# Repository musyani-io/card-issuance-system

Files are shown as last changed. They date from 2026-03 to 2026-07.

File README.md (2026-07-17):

# Smart ID Card Issuance Kiosk

A prototype university ID-card issuance system that combines a Raspberry Pi application, OCR-based card registration, local SQLite storage, student authentication, SMS/email credential delivery, and an Arduino Mega hardware-control prototype.

> **Project status:** Active prototype. The software modules are partly integrated, while physical card dispensing is still simulated in the current Kivy application.

---

## Table of Contents

- [Project Overview](#project-overview)
- [Current Implementation Status](#current-implementation-status)
- [System Workflow](#system-workflow)
- [Architecture](#architecture)
- [Technology Stack](#technology-stack)
- [Repository Structure](#repository-structure)
- [Kiosk Application Setup](#kiosk-application-setup)
- [Database Setup](#database-setup)
- [Mock University API Setup](#mock-university-api-setup)
- [Running the OCR Pipeline](#running-the-ocr-pipeline)
- [Running the Kiosk UI](#running-the-kiosk-ui)
- [Firmware Setup](#firmware-setup)
- [Testing](#testing)
- [Configuration Reference](#configuration-reference)
- [Security Design](#security-design)
- [Known Limitations](#known-limitations)
- [Development Priorities](#development-priorities)
- [Documentation and Hardware Files](#documentation-and-hardware-files)
- [License](#license)

---

## Project Overview

The project is intended to automate the storage and collection of university identity cards.

The repository currently contains four main parts:

1. **Raspberry Pi kiosk application**
   - Kivy touchscreen interface
   - Student registration-number entry
   - OTP verification
   - Temporary and permanent PIN handling
   - SQLite card and authentication records
   - Session timeout and lockout screens

2. **OCR and card-ingestion pipeline**
   - Camera image capture
   - Card contour detection
   - Perspective correction
   - Registration-number region extraction
   - Tesseract OCR
   - University API lookup
   - Local card-slot assignment

3. **Mock university database API**
   - Flask REST API
   - MySQL-backed student lookup
   - API-key authentication
   - Student-field normalization

4. **Hardware-control prototype**
   - Arduino Mega 2560 PlatformIO project
   - SPI frame reception from Raspberry Pi
   - Servo test routines
   - Hardware, PCB, mechanical, simulation, and datasheet files

---

## Current Implementation Status

| Subsystem | Current state |
| --- | --- |
| Kivy student collection interface | Implemented |
| Registration-number validation | Implemented |
| Local SQLite database | Implemented |
| OTP generation and verification | Implemented |
| Temporary PIN and permanent PIN storage | Implemented |
| Bcrypt credential hashing | Implemented |
| Authentication lockout logic | Implemented |
| SMS delivery through BRIQ Solutions | Implemented; requires credentials |
| Email delivery through Gmail SMTP | Implemented; requires credentials |
| University API client | Implemented |
| Flask/MySQL mock university API | Implemented; requires local configuration and database |
| Camera image capture | Implemented |
| Card contour and perspective correction | Implemented |
| Tesseract OCR extraction | Implemented |
| Card ingestion and three-slot assignment | Implemented |
| Raspberry Pi SPI sender | Basic two-byte status frames implemented |
| Arduino Mega SPI receiver | Basic frame reception implemented |
| Servo prototype | Implemented at firmware-test level |
| Staff batch-loading Kivy interface | Not integrated into `main.py` |
| Automatic motorised card dispensing | Not integrated; simulated in `main.py` |
| Complete carousel/conveyor control | Not implemented in the checked-in firmware |
| Production deployment and enclosure | Not complete |

The repository documentation has been updated to reflect the physical system. The firmware targets an **Arduino Mega 2560**, and the SQLite ingestion logic assigns a maximum of **three active slots** (0, 1, 2) matching the 3-compartment carousel design.

---

## System Workflow

### Card registration and ingestion

```text
Camera capture
      |
      v
Card contour detection
      |
      v
Perspective correction
      |
      v
Registration-number ROI extraction
      |
      v
Tesseract OCR
      |
      v
University API lookup
      |
      v
Generate OTP and temporary PIN when required
      |
      v
Store student, authentication, card, and audit records in SQLite
      |
      v
Send credentials through SMS and email
```

### Student card collection

```text
Idle screen
      |
      v
Enter registration number
      |
      v
Check local student and card record
      |
      v
Enter six-digit OTP
      |
      +-------------------------------+
      |                               |
      v                               v
Temporary PIN exists             Permanent PIN exists
      |                               |
      v                               |
Verify temporary PIN                  |
      |                               |
      v                               |
Create permanent PIN                  |
      +---------------+---------------+
                      |
                      v
Load assigned slot
                      |
                      v
Mark card as collected
                      |
                      v
Simulated dispensing delay
                      |
                      v
Confirmation screen
```

> The returning-student branch currently proceeds after OTP verification without displaying the permanent-PIN entry screen. The authentication module contains permanent-PIN verification logic, but that step is not connected to the returning-student path in `main.py`.

---

## Architecture

```mermaid
flowchart LR
    CAM[Camera or phone webcam] --> OCR[OpenCV and Tesseract OCR]
    OCR --> INGEST[Card ingestion service]
    API[Flask university API] --> INGEST
    MYSQL[(University MySQL database)] --> API
    INGEST --> SQLITE[(Local SQLite database)]
    INGEST --> SMS[BRIQ SMS API]
    INGEST --> EMAIL[Gmail SMTP]
    UI[Kivy touchscreen UI] --> SQLITE
    UI --> AUTH[OTP and PIN authentication]
    AUTH --> SQLITE
    UI -. basic status frames .-> SPI[Raspberry Pi SPI master]
    SPI --> MEGA[Arduino Mega 2560]
    MEGA --> SERVO[Servo prototype]
```

### Raspberry Pi application layer

The `kiosk_brain` application is responsible for:

- Kivy user-interface screens
- Student-session state
- Local database access
- OTP and PIN verification
- OCR processing
- University API communication
- SMS and email credential delivery
- Basic SPI transmission

### Local database layer

SQLite stores:

- Students
- Cards and assigned slots
- OTP and PIN hashes
- Authentication attempts and lockouts
- Audit events
- Batch metadata

### University API layer

The mock API provides:

```http
GET /students/<registration_number>
X-API-Key: <configured-key>
```

It reads student records from MySQL and normalizes alternative field names such as:

- `reg_number` or `registration_number`
- `last_name` or `surname`
- `phone` or `phone_number`
- `status` or `registration_status`

### Hardware-control layer

The current firmware is a PlatformIO Arduino project for the Mega 2560. It currently:

- Configures the Mega as an SPI slave
- Receives two-character ASCII frames
- Prints received frames through the serial monitor
- Runs prototype servo movement routines

It does not yet implement the complete carousel, conveyor, sensor, lock, or dispensing sequence described in the planning documents.

---

## Technology Stack

### Application

- Python
- Kivy
- OpenCV
- Tesseract OCR through `pytesseract`
- SQLite
- Requests
- Bcrypt
- `spidev`
- Pytest

### API

- Flask
- MySQL Connector/Python
- MySQL

### Firmware

- PlatformIO
- Arduino framework
- Arduino Mega 2560
- Servo library
- AVR SPI interrupt handling

### Hardware and design

- Altium project files
- KiCad files
- FreeCAD files
- Simulation files
- Component datasheets
- Raspberry Pi and embedded-controller planning documents

---

## Repository Structure

```text
card-issuance-system/
├── README.md
├── BUILD.md
├── docs/
│   ├── business/
│   ├── official/
│   ├── primary/
│   ├── carousel_3d_v2.html
│   └── kiosk_architecture.html
├── firmware/
│   ├── docs/
│   ├── include/
│   ├── src/
│   │   └── main.cpp
│   ├── test/
│   └── platformio.ini
├── hardware/
│   ├── Altium/
│   ├── FreeCAD/
│   ├── datasheets/
│   ├── kiCAD/
│   ├── simulations/
│   └── README.md
├── kiosk_brain/
│   ├── main.py
│   ├── config.example.py
│   ├── requirements.txt
│   ├── modules/
│   │   ├── api_client.py
│   │   ├── auth.py
│   │   ├── capture_image.py
│   │   ├── card_detector.py
│   │   ├── database.py
│   │   ├── ocr.py
│   │   ├── session_manager.py
│   │   ├── sms_client.py
│   │   └── spi_master.py
│   ├── db/
│   │   ├── DATABASE_DESIGN.md
│   │   ├── init_db.py
│   │   └── schema.sql
│   ├── ui/
│   │   ├── constants.py
│   │   ├── screens.py
│   │   ├── styled_widgets.py
│   │   └── styles.kv
│   └── tests/
│       ├── all_test.py
│       ├── test_auth.py
│       ├── test_ingest.py
│       ├── test_spi.py
│       └── OCR output-generation scripts
└── mock_db_api/
    ├── app.py
    ├── README.md
    └── requirements.txt
```

---

## Kiosk Application Setup

### 1. Clone the repository

```bash
git clone https://github.com/musyani-io/card-issuance-system.git
cd card-issuance-system/kiosk_brain
```

### 2. Install system dependencies

Install Python, Tesseract OCR, and the operating-system packages required by Kivy and OpenCV.

On Debian, Ubuntu, or Raspberry Pi OS:

```bash
sudo apt update
sudo apt install -y python3 python3-venv python3-pip tesseract-ocr
```

Raspberry Pi hardware access also requires SPI to be enabled:

```bash
sudo raspi-config
```

Open **Interface Options**, enable **SPI**, and reboot.

### 3. Create a Python virtual environment

```bash
python3 -m venv .venv
source .venv/bin/activate
python -m pip install --upgrade pip
pip install -r requirements.txt
```

### 4. Create the local configuration file

```bash
cp config.example.py config.py
```

The current example file contains the service and OCR settings, but it also needs a `Path` import and a local database path for the checked-in modules.

Add the following near the top of `config.py`:

```python
from pathlib import Path

BASE_DIR = Path(__file__).resolve().parent
DB_PATH = BASE_DIR / "db" / "kiosk.db"
```

Then update:

- BRIQ API credentials
- Gmail SMTP account and app password
- University API address and API key
- Camera device paths
- OCR parameters when necessary

Do not commit `config.py`.

---

## Database Setup

Initialize the local SQLite database from `kiosk_brain`:

```bash
python3 db/init_db.py
```

The default database is created at:

```text
kiosk_brain/db/kiosk.db
```

To clear records and recreate the schema:

```bash
python3 db/init_db.py --reset
```

### SQLite tables

| Table | Purpose |
| --- | --- |
| `students` | Local student information |
| `cards` | Card status, batch, and slot assignment |
| `authentication` | OTP, PIN, attempt counters, and lockout data |
| `audit_log` | Authentication and card-processing events |
| `batches` | Batch-loading statistics |

The current ingestion code uses three local slots:

```text
0, 1, 2
```

A slot remains occupied while its card status is not `collected`.

---

## Mock University API Setup

The mock API is optional when the local SQLite database already contains the records required by the kiosk UI. It is required for card ingestion through `ingest_card()` or the OCR pipeline.

### 1. Enter the API directory

```bash
cd ../mock_db_api
```

### 2. Create an environment

```bash
python3 -m venv .venv
source .venv/bin/activate
pip install -r requirements.txt
```

### 3. Create `config.py`

`mock_db_api/app.py` expects a local configuration file that is not committed to the repository.

Create `mock_db_api/config.py`:

```python
API_KEY = "test-key-12345"

DB_HOST = "localhost"
DB_PORT = 3306
DB_USER = "root"
DB_PASSWORD = "your-mysql-password"
DB_NAME = "card_issuance"
```

The API key must match `UNIVERSITY_API_KEY` in `kiosk_brain/config.py`.

### 4. Prepare MySQL

Create the configured database and a `students` table containing the student fields used by the application.

The API first searches by `reg_number` and falls back to `registration_number`.

Expected student information includes:

- Registration number
- First name
- Surname or last name
- Email address
- Phone number
- Programme
- Registration status

### 5. Run the API

```bash
python3 app.py
```

The default service address is:

```text
http://localhost:5000
```

Example request:

```bash
curl \
  -H "X-API-Key: test-key-12345" \
  http://localhost:5000/students/2022-04-09050
```

---

## Running the OCR Pipeline

Return to `kiosk_brain` and activate its virtual environment.

### Capture one image

```bash
python3 modules/capture_image.py
```

The capture module:

- Tries the configured video-device candidates
- Applies the configured width, height, and frame rate
- Warms up the camera
- Captures one frame
- Rotates the frame clockwise
- Saves it in the configured capture directory

### Run capture, OCR, and ingestion

```bash
python3 modules/ocr.py
```

The OCR pipeline performs:

1. Camera capture
2. Card contour detection
3. Perspective flattening
4. Registration-number ROI cropping
5. Grayscale and adaptive-threshold preprocessing
6. Tesseract OCR
7. Registration-number extraction
8. Student API lookup
9. SQLite ingestion
10. OTP and credential dispatch

Supported OCR patterns include:

```text
2022-04-09050
T/UDSM/2022/1234
```

An 11-digit compact number can also be reformatted into:

```text
XXXX-XX-XXXXX
```

### Ingest a known registration number without OCR

```bash
python3 -c \
"from modules.database import ingest_card; print(ingest_card('2022-04-09050'))"
```

Replace the example with a registration number that exists in the mock university database.

---

## Running the Kiosk UI

From `kiosk_brain`:

```bash
python3 main.py
```

The UI is configured for:

```text
800 × 400 pixels
```

### Current screens

- Idle
- Registration-number entry
- OTP entry
- PIN entry
- PIN setup
- Waiting
- Confirmation
- Error
- Locked

### Current validation values

| Setting | Value |
| --- | ---: |
| Registration-number length | 13 characters |
| OTP length | 6 digits |
| PIN length | 4 digits |
| Registration lookup attempts | 3 |
| OTP attempts | 3 |
| PIN attempts | 3 |
| Inactivity timeout | 15 seconds |
| Confirmation timeout | 15 seconds |
| Locked-screen display | 5 seconds |

The Kivy UI reads already-ingested records from SQLite. It does not perform card ingestion itself.

---

## Firmware Setup

The current firmware targets an **Arduino Mega 2560**.

### Requirements

Install PlatformIO Core or use PlatformIO inside Visual Studio Code.

### Build

```bash
cd firmware
pio run
```

### Upload

Connect the Mega 2560 and run:

```bash
pio run --target upload
```

### Open the serial monitor

```bash
pio device monitor --baud 115200
```

### Current firmware behaviour

The firmware currently:

- Attaches prototype servos to pins 22, 23, and 24
- Configures hardware SPI slave pins on the Mega
- Receives two-byte ASCII frames
- Prints received frames to the serial monitor
- Runs a servo movement test during startup

### Current SPI interface

Raspberry Pi configuration in `modules/spi_master.py`:

| Parameter  | Value |
| --- | --- |
| SPI bus | 0 |
| SPI device | 0 |
| Speed | 100 kHz |
| Mode | 0 |
| Frame type | Two-character ASCII |

Status frames:

| Frame | Meaning |
| ----- | --- |
| `00`  | Processing error |
| `1X`  | Processing success; `X` is the slot index |

The Mega hardware SPI pins are:

| Signal | Mega 2560 pin |
| --- | ---: |
| SS | 53 |
| MOSI | 51 |
| MISO | 50 |
| SCK | 52 |

Use a common ground between the Raspberry Pi and Arduino. Apply appropriate 5 V-to-3.3 V level shifting where required to protect the Raspberry Pi.

---

## Testing

From `kiosk_brain`:

```bash
pytest tests/test_auth.py tests/test_ingest.py tests/test_spi.py
```

The repository also contains scripts that generate intermediate OCR images for:

- Card detection
- Perspective correction
- Preprocessing
- ROI extraction
- OCR output inspection

These scripts are development utilities rather than normal unit tests.

---

## Configuration Reference

### Kiosk configuration

`kiosk_brain/config.py` controls:

- `DB_PATH`
- `UNIVERSITY_API_BASE_URL`
- `UNIVERSITY_API_KEY`
- `BRIQ_API_KEY`
- `BRIQ_SENDER_ID`
- `BRIQ_BASE_URL`
- `SMTP_EMAIL`
- `APP_PASSWORD`
- Camera device candidates
- Capture dimensions and frame rate
- Card-detection thresholds
- Perspective output size
- Registration-number ROI
- OCR preprocessing values

### Mock API configuration

`mock_db_api/config.py` controls:

- `API_KEY`
- `DB_HOST`
- `DB_PORT`
- `DB_USER`
- `DB_PASSWORD`
- `DB_NAME`

### Secrets

The following must remain outside version control:

- API keys
- SMTP app passwords
- MySQL passwords
- Production database addresses
- Any real student data

---

## Security Design

The authentication module includes:

- Cryptographically generated six-digit OTPs
- Cryptographically generated four-digit temporary PINs
- Bcrypt hashing for OTPs and PINs
- OTP expiry after 24 hours
- OTP lockout after repeated failures
- PIN lockout after repeated failures
- Temporary-to-permanent PIN transition
- Audit logging
- Session teardown and inactivity handling

### Authentication behaviour

- OTP lockout is configured for 30 minutes after the threshold is reached.
- PIN lockout is configured for 24 hours after the threshold is reached.
- Credentials are sent independently through SMS and email.
- Credential delivery is considered successful when at least one channel succeeds.
- Plaintext OTPs and PINs should never be stored in the database or written to production logs.

---

## Known Limitations

1. **Dispensing is simulated.**  
   `main.py` displays a simulated delay instead of commanding the physical dispenser.

2. **Card status is updated before physical confirmation.**  
   The current flow marks a card as `collected` before simulated dispensing completes. A production version should update the database only after receiving a verified hardware-success response.

3. **Returning-student permanent PIN is not wired into the UI flow.**  
   The authentication module supports permanent-PIN verification, but the current returning-student branch proceeds after OTP verification.

4. **The firmware is an early prototype.**  
   It receives SPI frames and tests servo movement but does not yet execute complete carousel or conveyor commands.

5. **Legacy planning references.**  
   Earlier design drafts mentioned STM32 controllers, a 3-byte binary protocol, 1 MHz SPI, and a 10-slot carousel. The actual system implementation uses an Arduino Mega 2560, a 2-byte ASCII frame protocol over 100 kHz SPI, and three software slots corresponding to the 3-compartment carousel.

6. **Staff batch-loading UI is not integrated.**  
   Card ingestion is available through the OCR module and database functions, not through the current Kivy `main.py` interface.

7. **Local configuration files are required.**  
   `kiosk_brain/config.py` and `mock_db_api/config.py` must be created locally.

8. **The example kiosk configuration needs two additions.**  
   The checked-in `config.example.py` uses `Path` and the application imports `DB_PATH`, but the example does not currently define both.

9. **The mock API requires a separately prepared MySQL schema.**  
   A MySQL student-table creation script is not included in `mock_db_api`.

10. **No production security boundary has been established.**  
    The development API uses a static API key and HTTP by default. Production deployment should use HTTPS, secret management, restricted network access, and stronger service authentication.

---

## Development Priorities

The following changes are required before a complete hardware demonstration:

1. Connect the returning-student flow to permanent-PIN verification.
2. Move `mark_card_collected()` after confirmed hardware dispensing.
3. Replace simulated dispensing with SPI command and acknowledgement handling.
4. Define one authoritative controller and protocol specification.
5. Implement carousel homing and slot movement.
6. Implement conveyor, ejector, lock, and sensor state machines.
7. Add SPI checksums, timeouts, retries, and fault codes.
8. Integrate the staff batch-loading workflow into the Kivy application.
9. Add a MySQL schema and seed data for `mock_db_api`.
10. Correct and expand the example configuration files.
11. Add end-to-end tests covering OCR, API, database, authentication, SPI, and physical dispensing.
12. Update older planning documents so they match the selected hardware.

---

## Documentation and Hardware Files

The repository includes:

- Business and concept documents
- Semester reports
- Presentation files
- Architecture diagrams
- Mechanical carousel visualisation
- PCB design directories
- CAD files
- Simulations
- Component datasheets
- Build-progress notes

Some of these files describe planned architecture rather than the behaviour of the current source code. For implementation work, use the checked-in source files as the current reference.

---

## License

No software license file is currently included in the repository. Add a license before distributing or accepting external contributions.

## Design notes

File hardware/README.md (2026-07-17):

# Hardware Implementation

**Status**: Phase 5 (Mechanical Prototype) — Active prototyping. Target platform is the Arduino Mega 2560 with the 2-byte ASCII SPI protocol.

This section outlines the hardware architecture, pin mappings, and integration strategy for motor control, power distribution, sensing, and inter-controller communication.

---

## Power Distribution Architecture

**Topology**: Single 220VAC-to-12VDC primary power supply with step-down logic regulation and star common ground.

- **Primary Source**: 220VAC-to-12VDC switching power supply.
- **Logic Power**: An LM2596 buck converter steps down the 12V rail to 5VDC to power the Raspberry Pi 5, the Arduino Mega 2560, and logic sensors.
- **Common Reference**: All grounds (12V power supply negative terminal, LM2596 input/output grounds, Raspberry Pi ground, and Arduino Mega ground) are tied together at a single common reference point (star ground configuration) to eliminate ground loop noise.

| Rail | Voltage | Components | Regulation / Source | Grounding |
| --- | --- | --- | --- | --- |
| **Primary** | 12V | Stepper drivers, solenoid lock, servos | 220VAC to 12VDC PSU | Single-Point Common Ground |
| **Logic** | 5V | Raspberry Pi 5, display, Arduino Mega, sensors | LM2596 Buck Converter | Single-Point Common Ground |

**Implementation Tasks**:
1. Mount the 220VAC-to-12VDC primary switching power supply securely.
2. Connect the LM2596 buck converter to the 12V rail and calibrate its output to exactly 5.0V before connecting any logic components.
3. Establish a single ground terminal block where all grounds are physically joined at one point.
4. Add safety fuses where appropriate (e.g. on the primary 12V rail).
5. Use adequate gauge wire (e.g. AWG 16–18 for power paths, AWG 22 for logic grounds) to prevent voltage drops.

---

## Motor Driver & Stepper Motor Control

**Architecture**: 28BYJ-48 geared stepper motor (5V/12V) with ULN2003 Darlington driver board.

**Driver Connection**:
- **Inputs**: IN1, IN2, IN3, IN4 connected to Arduino Mega digital output pins.
- **Power**: 5V/12V (depending on motor variant) + GND.
- **Outputs**: 4-phase coil connector to the 28BYJ-48 stepper motor.

**Arduino Mega Pin Mapping**:
- `IN1` ──→ Digital Pin 30
- `IN2` ──→ Digital Pin 31
- `IN3` ──→ Digital Pin 32
- `IN4` ──→ Digital Pin 33

> [!NOTE]
> The Arduino code constructs the stepper interface using `Stepper stepper(2048, 30, 32, 31, 33)` (IN1, IN3, IN2, IN4 pin order) to match the correct phase sequence required by the 28BYJ-48.

**Tuning Parameters**:
- **Steps per full rotation**: 2048 steps (geared down).
- **Speed**: 5 RPM (configured in firmware to maximize torque and prevent mechanical slippage).
- **Homing and Carousel Compartments**:
  - Carousel has 3 compartments: A, B, and C (Failure/Reject slot).
  - Homing aligns to Compartment A (0° / 0 steps).
  - Compartment B (120°) is located at 683 steps.
  - Compartment C (240°) is located at 1365 steps.

---

## Servo Motor Control (SG90 Servo)

**Servo**: Single SG90 analog micro-servo for the card holder / front gate release mechanism.

**Control Signal**: PWM at 50 Hz, 544–2400µs pulse width.
- **Origin position**: 544µs (0° hold position).
- **Active release position**: Mapped to 70° in the firmware to retract the card gate.

**Arduino Mega Connection**:
- **Vcc**: 5V Logic Rail (from LM2596 output)
- **GND**: Common Ground
- **Signal**: Digital Pin 22 (PWM)

**Firmware Logic**:
To prevent sudden jumps on startup, the pulse width is preloaded to the origin pulse (544µs) before attaching the servo object. The servo moves smoothly using a microsecond-stepping sweep routine.

---

## Raspberry Pi 5 ↔ Arduino Mega 2560 SPI Communication

**Bus Specification**: SPI Mode 0, 100 kHz clock speed. 

**Physical Interconnect**:
- **Raspberry Pi 5 (Master)**:
  - GPIO 11 (SCLK) ──→ Mega Pin 52 (SCK)
  - GPIO 10 (MOSI) ──→ Mega Pin 51 (MOSI)
  - GPIO 9  (MISO) ───→ Mega Pin 50 (MISO)
  - GPIO 8  (CE0)  ───→ Mega Pin 53 (SS, active low)
  - Common Ground  ───→ GND (tied to the single-point common ground)

> [!IMPORTANT]
> The Arduino Mega operates at 5V logic, while the Raspberry Pi 5 operates at 3.3V. You **MUST** use an appropriate 5V-to-3.3V logic level shifter on the MISO line (Mega TX to Pi RX) to protect the Raspberry Pi GPIO pins.

**2-Byte ASCII Protocol**:
Every transmission frame consists of exactly **2 ASCII characters** without checksum bytes, terminated by a null character in the receiver buffer.

### Status and Routing Frames (Pi → Mega)

| ASCII Frame | Transaction Type | Action / Target Meaning |
| --- | --- | --- |
| `"10"` | Ingestion (OCR)  | Route Compartment A to Entrance (0°) and release card |
| `"11"` | Ingestion (OCR)  | Route Compartment B to Entrance (120°) and release card |
| `"12"` | Ingestion (OCR)  | Route Compartment C to Entrance (240°) and release card |
| `"00"` | Ingestion (OCR)  | OCR Error/Failure: Route Compartment C to Entrance (240°) |
| `"20"` | Collection (UI)  | Route Compartment A to Exit (180°) and await pickup |
| `"21"` | Collection (UI)  | Route Compartment B to Exit (300°) and await pickup |
| `"FF"` | Collection (UI)  | UI Transaction Failure / Cancelled |

---

## Integration Checkpoint

Before moving to full system integration, validate in sequence:
1. **Power Rails**: Verify stable 12V and 5V outputs under load; check for noise/ripple.
2. **Stepper driver**: Test rotation in both directions; verify that speed is set to 5 RPM to ensure torque.
3. **Servo Gate**: Confirm card holder gate opens to 70° and returns to origin (0°).
4. **SPI Loopback**: Send characters `"10"`, `"11"`, `"20"`, etc., from `spi_master.py` and confirm serial outputs on the Arduino Mega.

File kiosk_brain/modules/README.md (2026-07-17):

# Kiosk Brain — Raspberry Pi 5 (4GB) Application

The kiosk-brain is the intelligent application layer of the Smart ID Card Distribution Kiosk, running on Raspberry Pi 5 (4GB) with Python 3.11. It manages the entire student-facing and staff-facing workflow, OCR image processing, authentication, database persistence, SMS dispatch, and hardware control via SPI protocol.

## Architecture Overview

### High-Level Control Flow

```bash
IDLE Screen
    ↓ [on touch/swipe events]
    ├─→ Staff Door Unlock Path
    │    └─ STAFF_PIN Screen (bcrypt PIN validation)
    │         ├─→ [3× fail] LOCKED Screen (24h hard lockout)
    │         └─→ [correct] CHECKLIST Screen
    │              ├─ Pre-scan validation (staff device serial, time, batch count)
    │              └─ BATCH Progress Screen
    │                  ├─ Conveyor 1 IR trigger → CSI camera capture
    │                  ├─ OCR pipeline (OpenCV preprocessing + Tesseract extraction)
    │                  ├─ [OCR fail] → Servo flap divert to reject bin
    │                  ├─ [OCR pass] → Regex validation + confidence gating
    │                  ├─ HTTPS query university API → student data fetch
    │                  ├─ [API timeout] → queue card as pending_lookup, retry background
    │                  ├─ SPI status frames ("1X" / "00")
    │                  ├─ Africa's Talking SMS dispatch (OTP for returning, OTP+PIN for first-year)
    │                  └─ Loop until conveyor empty → SUMMARY (batch complete)
    │
    └─→ Student Card Collection Path
         ├─→ HOME Screen (path selector)
         │    ├─→ Button [Collection with OTP]
         │    │    └─ OTP Screen (6-digit input, rate-limited resend)
         │    │         ├─ [3× fail] 30-min soft lockout
         │    │         └─ [correct] PIN_SELECT Screen
         │    │              └─ [existing PIN path or temp PIN + force-change]
         │    │
         │    └─→ Button [Expired Card Scan]
         │         ├─ Servo latch activates (card clamped in slot)
         │         ├─ USB camera frame capture (expired card registration number)
         │         ├─ OCR extracts reg number
         │         ├─ Lookup student in SQLite
         │         └─ → OTP Screen (same as above)
         │
         ├─→ PIN Screen (4–6 digit, bcrypt verified)
         │    ├─ [3× fail] 24h hard lockout (audited for administrator)
         │    └─ [correct] CONFIRM Screen
         │
         ├─→ CONFIRM Screen (show student name, programme, card info)
         │    ├─ [confirm button] → SUCCESS
         │    │    ├─ SPI status frame "2X"
         │    │    ├─ Servo activation to open gate
         │    │    ├─ [eject success] → StudentCollection audit event
         │    │    └─ Timer 30s → auto-logout back to IDLE
         │    │
         │    └─ [cancel button] → IDLE (cascade: Servo RELEASE_CARD, SMS notification)
         │
         └─→ LOCKED Screen (24h hard lockout)
              └─ [display admin contact info]
              └─ Auto-logout after 60s
```

### Module Responsibilities

| Module | Purpose | Key Dependencies |
| --- | --- | --- |
| `main.py` | Kivy app entry point, ScreenManager initialization | Kivy, config, logging |
| `config.py` | Environment variables, API keys, timeout constants | pathlib, os |
| `api_client.py` | HTTPS wrapper for university DB (with mDNS support) | requests, urllib3 |
| `auth.py` | OTP generation, bcrypt PIN verification, lockout state machine | bcrypt, secrets, sqlite3 |
| `database.py` | SQLite schema, transactions, batch operations | sqlite3, datetime |
| `ocr.py` | Image preprocessing, Tesseract invocation, regex validation | opencv-python, pytesseract |
| `session_manager.py` | Per-session state lifecycle, explicit teardown | dataclasses |
| `sms_client.py` | Africa's Talking SDK wrapper, retry queue | africastalking |
| `spi_master.py` | SPI frame transmission to lower controller | spidev |
| `ui/screens.py` | Kivy Screen subclasses, event handlers | Kivy |
| `ui/styles.kv` | Widget layouts, event bindings | Kivy (.kv DSL) |

## Installation & Configuration

### Prerequisites

- **Python 3.11**: Required for type hints and performance

  ```bash
  sudo apt install python3.11 python3.11-venv
  ```

- **System Libraries**

  ```bash
  # For OpenCV and Tesseract
  sudo apt install libopencv-dev libsm6 libxrender-dev libxext-dev
  sudo apt install tesseract-ocr libtesseract-dev
  sudo apt install libatlas-base-dev libjasper-dev libtiff5 libharfbuzz0b libwebp6

  # For SPI communication
  sudo apt install python3-spidev

  # For mDNS support
  sudo apt install avahi-daemon
  ```

### Python Virtual Environment

```bash
cd kiosk-brain
python3.11 -m venv venv
source venv/bin/activate
pip install --upgrade pip wheel setuptools
pip install -r requirements.txt
```

### Configuration File (`config.py`)

```python
# config.py structure — CRITICAL for deployment

API_KEY_UNIVERSITY = "your-api-key-here"  # Bearer auth
API_KEY_AFRICAS_TALKING = "your-at-api-key"
SMS_SENDER_NAME = "UNIV_ID"

UNIVERSITY_BASE_URL = "http://university-db.local:5000"  # mDNS resolution
UNIVERSITY_API_TIMEOUT = 5.0  # seconds
UNIVERSITY_API_RETRIES = 3

SMS_GATEWAY_TIMEOUT = 10.0
SMS_RETRY_INTERVAL = 900  # 15 minutes

OTP_LENGTH = 6
OTP_VALIDITY_HOURS = 24
OTP_RETRY_SOFT_LOCKOUT_MINUTES = 30
OTP_MAX_ATTEMPTS = 3

PIN_LENGTH_MIN = 4
PIN_LENGTH_MAX = 6
PIN_MAX_ATTEMPTS = 3
PIN_LOCKOUT_HOURS = 24

STAFF_PIN = "b'$2b$12$...'"  # bcrypt hash (pre-computed, never store plaintext)
STAFF_PIN_MAX_ATTEMPTS = 3
STAFF_PIN_LOCKOUT_HOURS = 24

KIVY_WINDOW_WIDTH = 800
KIVY_WINDOW_HEIGHT = 480
KIVY_FONT_SIZE_TITLE = 24
KIVY_FONT_SIZE_NORMAL = 18

SESSION_IDLE_TIMEOUT_SECONDS = 90  # Auto-logout duration
SESSION_COLLECTION_SUCCESS_DISPLAY_SECONDS = 30

OCR_CONFIDENCE_THRESHOLD = 0.95
OCR_TESSERACT_CONFIG = "--psm 7 --dpi 300"
OCR_TIMEOUT_SECONDS = 5.0

DATABASE_PATH = "/home/pi/card-issuance-system/kiosk-brain/data/kiosk.db"
LOG_PATH = "/home/pi/card-issuance-system/kiosk-brain/data/logs"

SPI_DEVICE = "/dev/spidev0.0"
SPI_SPEED_HZ = 100_000  # 100 kHz clock

# Email for escalated audit events (admin review)
ADMIN_CONTACT_EMAIL = "admin@university.edu"
ADMIN_CONTACT_PHONE = "+255..."
```

⚠️ **Security Note**: Never commit `config.py` with real API keys. Use environment variables:

```bash
export AFRICAS_TALKING_KEY="..."
export UNIVERSITY_API_KEY="..."
```

### Database Initialization

```bash
cd db
python init_db.py
```

This creates `kiosk.db` with tables: `students`, `cards`, `authentication`, `audit_log`, `batches`.

## Python Modules Reference

### `api_client.py`

**Purpose**: HTTPS wrapper for university student database with automatic mDNS resolution.

**Public Interface**:

```python
class UniversityAPIClient:
    def __init__(self, base_url: str, api_key: str, timeout: float = 5.0):
        pass

    def get_student(self, reg_number: str) -> dict:
        """
        Fetch student data by registration number.

        Returns:
            {
                "reg_number": "T/UDSM/0001/2021",
                "name": "Jane Doe",
                "programme": "Computer Science",
                "phone": "+255123456789",
                "status": "active" | "inactive" | "suspended"
            }

        Raises:
            APITimeoutError: If request exceeds timeout
            APIConnectionError: If network unavailable
            StudentNotFoundError: If reg_number not exists
        """
```

**Error Handling**:

- Timeouts: 5-second hard limit, 3 retries with exponential backoff (1s, 2s, 4s)
- Network failure: Card queued in `batches` table as `pending_lookup`, background thread retries every 2 minutes
- HTTP 404: Student record not found, card stored with status `missing_student`
- HTTP 403 (inactive/suspended): Card stored with status `hold`, no SMS dispatched

### `auth.py`

**Purpose**: Two-factor authentication with bcrypt hashing and lockout state machine.

**Public Interface**:

```python
class AuthenticationManager:
    def __init__(self, db_path: str):
        pass

    def generate_otp(self) -> str:
        """
        Generate 6-digit OTP using secrets.randbelow(1_000_000).
        Returns zero-padded string "000123".
        """

    def store_otp(self, reg_number: str, otp: str, validity_hours: int = 24) -> bool:
        """
        Hash OTP with bcrypt, store in DB with expiry timestamp.
        Returns True if successful.
        """

    def verify_otp(self, reg_number: str, otp_input: str) -> tuple[bool, str]:
        """
        Verify OTP against stored hash.

        Returns:
            (True, "valid") - OTP correct and within 24h window
            (False, "expired") - Correct but > 24h old
            (False, "mismatch") - Wrong OTP
            (False, "soft_lockout_30min") - 3× consecutive failures
        """

    def generate_pin(self) -> str:
        """Generate temporary PIN for first-year students."""

    def verify_pin(self, reg_number: str, pin_input: str) -> tuple[bool, str]:
        """
        Verify PIN against bcrypt hash.

        Returns:
            (True, "valid") - PIN correct
            (False, "mismatch") - Wrong PIN
            (False, "hard_lockout_24h") - 3× consecutive failures (audited)

        Also tracks lockout event in audit_log for administrator review.
        """

    def set_pin(self, reg_number: str, new_pin: str) -> bool:
        """
        Store new PIN as bcrypt hash. Called on first-year student's
        first collection visit (forces temporary PIN change).
        """
```

**Lockout Events Logged to `audit_log`**:

- `otp_verify_fail`: Each incorrect OTP attempt
- `otp_lockout`: Soft lockout after 3 OTP failures (30 minutes)
- `pin_verify_fail`: Each incorrect PIN attempt
- `pin_lockout`: Hard lockout after 3 PIN failures (24 hours, escalated to admin)

### `database.py`

**Purpose**: SQLite wrapper with transaction management and batch operations.

**Public Interface**:

```python
class KioskDatabase:
    def __init__(self, db_path: str):
        pass

    def add_student(self, reg_number: str, name: str, programme: str,
                    phone: str, status: str = "active") -> bool:
        """Insert student record (called after university API fetch)."""

    def get_student(self, reg_number: str) -> dict | None:
        """Lookup student by registration number."""

    def add_card_batch(self, batch_id: str, staff_id: str, count: int) -> bool:
        """Create batch record before staff loading session starts."""

    def add_card_to_carousel(self, reg_number: str, batch_id: str,
                             carousel_slot: int, sms_status: str = "pending") -> bool:
        """Assign card to carousel slot and track SMS status."""

    def mark_card_collected(self, reg_number: str) -> bool:
        """Update card status to 'collected' and log event."""

    def mark_card_rejected(self, reason: str) -> bool:
        """Update card status to 'rejected' (OCR fail, API error, etc.)."""

    def get_audit_log(self, limit: int = 100) -> list[dict]:
        """Retrieve recent audit events for administrator review."""

    def execute_transaction(self, *queries: tuple[str, list]) -> bool:
        """
        Execute multiple SQL queries in atomic transaction.

        Usage:
            db.execute_transaction(
                ("INSERT INTO students ...", [args]),
                ("UPDATE batches ...", [args]),
                ("INSERT INTO audit_log ...", [args])
            )
        """
```

**Transaction Safety**:

- All multi-table writes wrapped in `BEGIN → COMMIT` or `ROLLBACK`
- Corruption guard: UPS ensures clean Pi shutdown (SQLite checkpoint on exit)
- Concurrent access: Only main thread writes; background thread only appends to audit_log

### `ocr.py`

**Purpose**: Image preprocessing and character extraction for ID card registration numbers.

**Pipeline Stages**:

1. **Acquire frame**: CSI camera (triggerred by Conveyor 1 IR) or USB camera (expired slot IR)
2. **Grayscale**: `cv2.cvtColor(frame, cv2.COLOR_BGR2GRAY)`
3. **Adaptive threshold**: `cv2.adaptiveGaussianThreshold()` (handles uneven lighting)
4. **Deskew**: Hough line detection → rotation correction
5. **ROI crop**: Extract registration number field (template-matched)
6. **Sharpen**: Contrast enhancement via CLAHE
7. **Tesseract**: `--psm 7 --config alphanumeric-whitelist`

**Public Interface**:

```python
class OCREngine:
    def __init__(self, tesseract_config: str = "--psm 7", confidence_threshold: float = 0.95):
        pass

    def process_frame(self, image: np.ndarray) -> tuple[str | None, float]:
        """
        Process raw camera frame to extracted registration number.

        Args:
            image: BGR frame from camera (numpy array)

        Returns:
            (reg_number, confidence) if extraction succeeds
            (None, 0.0) if below confidence threshold or OCR fails

        Raises:
            OCRTimeoutError: If processing exceeds 5 seconds
        """

    def validate_format(self, reg_number: str) -> bool:
        """
        Validate against university format (regex pattern).
        Example: "T/UDSM/0001/2021" or "T/UDSM/0012/2022"
        """
```

**Error Handling**:

- Low confidence → Servo flap diverts card physically to reject bin (never enters carousel)
- Timeout (>5s) → Card marked as `ocr_timeout`, manual review required
- Format mismatch → Card marked as `ocr_format_invalid`

### `session_manager.py`

**Purpose**: Per-session state machine with explicit lifecycle management.

**State Machine**:

```python
@dataclass
class Session:
    session_id: str
    reg_number: str
    student_name: str
    programme: str
    carousel_slot: int
    auth_factor_1_passed: bool = False  # OTP verified
    auth_factor_2_passed: bool = False  # PIN verified
    session_type: str = "student"       # "student" or "staff"
    created_at: datetime = field(default_factory=datetime.now)

    def clear(self):
        """
        CRITICAL: Called on ALL exit paths (success, cancel, timeout, lockout).
        Resets state to prevent carryover to next session.

        Exit paths:
        - SUCCESS: Card dispensed, SMS sent, session logged
        - CANCEL: User tapped back button, servo releases card/latch
        - TIMEOUT: 90 seconds inactivity, auto-cleared
        - LOCKOUT: 24h PIN lockout or staff PIN wrong × 3
        - ERROR: Network failure, OTP expiry, etc.
        """
```

**Public Interface**:

```python
class SessionManager:
    def __init__(self):
        pass

    def create_session(self, reg_number: str, session_type: str = "student") -> Session:
        """Initialize new session with empty state."""

    def get_current_session(self) -> Session | None:
        """Retrieve active session (returns None if idle)."""

    def clear_session(self):
        """CRITICAL: Explicit teardown called on every exit path."""
```

### `sms_client.py`

**Purpose**: Africa's Talking SMS integration with retry queue.

**Public Interface**:

```python
class SMSClient:
    def __init__(self, api_key: str, sender_name: str):
        pass

    def send_otp_sms(self, phone: str, otp: str, student_name: str = "") -> bool:
        """
        Dispatch OTP to student phone.

        Message template: "Your ID card is ready. OTP: 847291. Collect 24/7."

        Returns True if accepted by SMS gateway (does not guarantee delivery).
        Failed sends queued in SQLite for retry.
        """

    def send_otp_and_pin_sms(self, phone: str, otp: str, temp_pin: str,
                             student_name: str = "") -> bool:
        """
        Dispatch OTP + temporary PIN to first-year student.

        Message template: "OTP: 847291 | Temp PIN: 3829. Change PIN on first visit."
        """

    def retry_failed_sends(self) -> int:
        """
        Background thread entrypoint: Retry SMS sends marked as failed every 15 minutes.
        Returns count of successfully retransmitted messages.
        """
```

**Error Handling**:

- API timeout: Queue in SQLite `batches` table, retry interval 15 minutes
- Invalid phone: Marked as `sms_invalid_phone`, no retry
- Rate limit (Africa's Talking): Exponential backoff
- Network failure: Same as API timeout, automatic retry

### `spi_master.py`

**Purpose**: SPI helper for transmitting 2-byte ASCII status frames to the lower controller (Arduino Mega 2560).

**Frame Format**:
Every transmission frame consists of exactly 2 ASCII characters representing the processing transaction status. No checksum byte is appended.

- Ingestion (OCR) Success: `"1X"` where `X` is the slot index (`0`, `1`, `2`)
- Ingestion (OCR) Failure: `"00"`
- Collection (UI) Success: `"2X"` where `X` is the slot index (`0`, `1`, `2`)
- Collection (UI) Failure: `"FF"`

**Public Interface**:
- `send_spi_message(message: str) -> list[int]`: Lower-level SPI transmission using `spidev` at 100 kHz clock speed. Opens and closes the SPI port dynamically to prevent bus locking.
- `send_status(success: bool, slot_index: int | None = None, is_ui: bool = False) -> str`: Higher-level wrapper to formulate the status frame and transmit it.

### `ui/screens.py`

**Purpose**: Kivy Screen subclasses for all user-facing workflows.

**Screen Classes**:

```python
class IDLEScreen(Screen):
    """Always-visible idle state, awaits staff unlock or student tap."""

class STAFFPINScreen(Screen):
    """PIN entry for staff (3 attempts before 24h lockout)."""

class CHECKLISTScreen(Screen):
    """Pre-batch validation (call staffing checklist)."""

class BATCHScreen(Screen):
    """Live batch loading progress (card count, estimated time, OCR errors)."""

class BATCHSUMMARYScreen(Screen):
    """Batch complete — show totals, SMS status, errors."""

class HOMEScreen(Screen):
    """Student path selector: [OTP Collection] [Expired Card Scan]."""

class OTPINPUTScreen(Screen):
    """6-digit OTP entry with rate-limited resend."""

class PININPUTScreen(Screen):
    """PIN entry (existing or temporary for first-year)."""

class CONFIRMScreen(Screen):
    """Show student info, confirm collection."""

class SUCCESSScreen(Screen):
    """Card dispensed, SMS sent, auto-logout in 30s."""

class LOCKEDScreen(Screen):
    """24h lockout (admin contact info), auto-logout in 60s."""
```

**Event Handlers**:

- Timeout: `on_idle_timeout()` → `session_manager.clear_session()` → Return to IDLE
- Cancel: `on_cancel_button()` → Release servo/latch → Clear session → Return to IDLE
- Success: `on_confirm_button()` → SPI ROTATE + EJECT → Log to audit → Clear session → SUCCESS screen

### `ui/styles.kv`

**Purpose**: Kivy Layout language (.kv file) defining widget tree and event bindings.

**Key Sections**:

- Global font sizes (18px minimum for arm's length readability on 7" screen)
- Color scheme (high contrast for outdoor/bright sunlight)
- Touch event bindings (buttons, text inputs, back swipe)
- Screen transitions (fade, slide)

## Testing

### Unit Tests (`tests/`)

Run all tests:

```bash
cd tests
pytest -v
```

#### `test_auth.py`

- bcrypt hash generation and verification
- OTP generation (6-digit, zero-padded)
- Soft lockout after 3 OTP failures (30 minutes)
- Hard lockout after 3 PIN failures (24 hours, audited)
- PIN change for first-year students

#### `test_ocr.py`

- Preprocessing pipeline (grayscale, threshold, deskew)
- Tesseract extraction with alphanumeric whitelist
- Regex format validation
- Confidence threshold gating (low-confidence cards diverted)
- Timeout handling (>5 seconds)

#### `test_spi.py`

- Frame encoding/decoding
- Checksum calculation (XOR)
- Command dispatch to mock Arduino Mega via loopback

### Integration Tests

```bash
# Mock API running with sample data
python ../mock-db-api/app.py &

# Run full workflow simulation
pytest tests/test_integration.py -v
```

**Test Scenarios**:

- Staff PIN login → Batch loading → Card OCR → API fetch → SMS dispatch → Carousel rotation
- Student OTP entry → PIN verification → Carousel slot collection → Success
- Lockout escalation: 3× PIN fail → 24h lockout → Audit log → Admin notification

## Logging & Monitoring

### Application Logs

```
/home/pi/card-issuance-system/kiosk-brain/data/logs/
├── kiosk_YYYY-MM-DD.log       # Daily application logs
├── ocr_YYYY-MM-DD.log         # OCR pipeline diagnostics
└── spi_YYYY-MM-DD.log         # SPI command trace
```

### Audit Log (SQLite)

```sql
SELECT * FROM audit_log
WHERE timestamp > datetime('now', '-1 day')
ORDER BY timestamp DESC;
```

**Event Types**:

- `session_start`: Student or staff initiates session
- `otp_sent`: SMS dispatched successfully
- `otp_verify_fail`: Incorrect OTP (with attempt count)
- `pin_verify_fail`: Incorrect PIN (with attempt count)
- `otp_lockout`: 3 OTP failures → 30-min cooldown
- `pin_lockout`: 3 PIN failures → 24h lockout (escalated to admin)
- `collection_success`: Card dispensed successfully
- `card_rejected_ocr`: OCR confidence below threshold

## Performance Tuning

| Component | Bottleneck | Mitigation |
| --- | --- | --- |
| **OCR** | Tesseract processing (1–3 seconds per frame) | Pre-process image quality, ROI tuning |
| **API call** | Network latency (mDNS lookup + HTTPS) | Connection pooling, keep-alive |
| **SMS dispatch** | Africa's Talking rate limit | Queue failures, background retry |
| **SPI latency** | Motor response time | Configure SPI clock speed (currently 100 kHz) |
| **Kivy rendering** | GPU fill rate on 7" display | Reduce animation frame count, optimize .kv layouts |

## Troubleshooting

### Common Issues

| Issue | Cause | Solution |
| --- | --- | --- |
| **Pi cannot reach university-db.local** | mDNS not resolved | Check avahi-daemon running on mock API laptop |
| **OCR accuracy very low** | Poor card lighting | Adjust conveyor LED brightness, check ROI crop bounds |
| **SPI timeout (motor stuck)** | Arduino Mega firmware crash | Check serial monitor logs, reload firmware |
| **Kivy display corruption** | GPU memory exhaustion | Reduce concurrent animations, check DSI ribbon connection  |
| **SMS not dispatched** | Invalid API key or rate limit | Check config.py, monitor audit log for `sms_failed` status |
| **Database file corruption after power loss** | Incomplete checkpoint | Verify UPS backup working (5V rail hold time) |

## Deployment Checklist

- [ ] Python 3.11 and dependencies installed
- [ ] Database initialized (`python db/init_db.py`)
- [ ] Africa's Talking API key loaded in config.py
- [ ] University database mDNS name resolvable
- [ ] Staff PIN hashed in config.py (never plaintext)
- [ ] Kivy runs on framebuffer (DSI display intact)
- [ ] SPI communication verified (GPIO connected to Arduino Mega)
- [ ] Systemd service enabled for autostart
- [ ] Camera calibration (CSI focus, USB angle)
- [ ] Test batch with sample cards
- [ ] Test student OTP/PIN workflows

## References

- **Kivy Documentation**: https://kivy.org/doc/
- **OpenCV API**: https://docs.opencv.org/
- **Tesseract OCR**: https://github.com/UB-Mannheim/tesseract/wiki
- **Africa's Talking SDK**: https://africastalking.com/sms/api
- **SQLite**: https://www.sqlite.org/
- **Python spidev**: https://github.com/doceme/py-spidev

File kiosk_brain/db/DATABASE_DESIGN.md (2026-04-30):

# Database Design Guide

## Overview

The SQLite database is the kiosk's source of truth. It stores student records, cards, authentication credentials, audit logs, and batch metadata.

---

## Key Design Decision 1: Email + SMS Credential Delivery

### Purpose

The `email` field in the `students` table enables **dual-channel credential delivery**. OTP and temporary PINs are sent to both the student's registered email and phone number for reliability and accessibility.

**Advantages:**

- **Redundancy** — If SMS fails (network, provider issues), email delivery succeeds
- **Accessibility** — Some students may not have active SMS receive (international numbers, spotty coverage)
- **Industry Standard** — Multi-channel 2FA is the modern security best practice

### Implementation

Each student record has:

- `email` — University email (TEXT, can be NULL for edge cases)
- `phone_number` — Mobile phone for SMS (TEXT, can be NULL)

When credentials are generated:

```bash
send_credentials(email, phone_number, otp, temp_pin=None):
  - Send SMS via Africa's Talking if phone_number exists
  - Send email via SMTP (Gmail/University SMTP) if email exists
  - Log failures separately for each channel
  - Do NOT fail the entire batch if one channel fails
```

**Message Examples:**

For **Returning Students** (no temp PIN):

- **SMS:** `"Your ID card is ready. OTP: 847291. Collect 24/7."`
- **Email:** `Subject: Your ID Card Claim OTP`  
  `Your OTP is: 847291 (valid 24 hours)`

For **First-Year Students** (with temp PIN):

- **SMS:** `"OTP: 847291 | Temp PIN: 3829. Change PIN on first visit."`
- **Email:** `Subject: Your ID Card Claim - OTP and Temporary PIN`  
  `OTP: 847291 | Temporary PIN: 3829 (Change on first collection)`

---

## Key Design Decision 2: `is_temp_pin` Column

### Purpose

The `is_temp_pin` column in the `authentication` table distinguishes between:

- **Temporary PINs** (`is_temp_pin = TRUE`) — System-generated 4-digit codes given to **first-year students** on their first card collection
- **Permanent PINs** (`is_temp_pin = FALSE`) — User-chosen codes set by students after first collection or used by **returning students** who already have a PIN

### Workflow

#### First-Year Student (New to System)

1. **Card Loaded into Kiosk** — OCR reads their registration number during staff batch loading
2. **SMS Sent** — `send_otp_sms()` generates both:
   - A 6-digit OTP (random, cryptographically secure)
   - A 4-digit temporary PIN (random, generated by `generate_temp_pin()`)
   - Both are hashed before storage
3. **Database State After SMS**

   ```bash
   authentication table:
   - otp_hash = bcrypt(otp)
   - otp_expiry = now + 24 hours
   - pin_hash = bcrypt(temp_pin)
   - is_temp_pin = TRUE  ← Marks this as temporary
   - failed_otp_attempts = 0
   - failed_pin_attempts = 0
   ```

4. **Student Enters OTP** → Successfully verified via `verify_otp()`
5. **Student Enters Temp PIN** → Successfully verified via `verify_pin()`
6. **Check `is_temp_pin` Flag** → If TRUE:
   - Force the **PIN Setup Screen** → Student enters a new permanent PIN twice to confirm
7. **Set Permanent PIN**

   ```sql
   UPDATE authentication
   SET pin_hash = bcrypt(new_pin), is_temp_pin = FALSE
   WHERE registration_number = ?
   ```

8. **Confirm Collection** → Card dispensed, session ends

#### Returning Student (Has Prior PIN)

1. **Card Scanned via Expired Card Slot** → OCR reads their old card
2. **Database Already Has Record** → From previous year, `is_temp_pin = FALSE` (permanent PIN)
3. **OTP Generated and Sent**

   ```bash
   authentication table:
   - otp_hash = bcrypt(otp)
   - otp_expiry = now + 24 hours
   - pin_hash = [unchanged — still their permanent PIN]
   - is_temp_pin = FALSE  ← Still permanent, not temp
   ```

4. **Student Enters OTP** → Verified
5. **Student Enters PIN** → Verified against their existing PIN hash
6. **Check `is_temp_pin` Flag** → If FALSE:
   - Skip PIN setup screen, proceed directly to **Confirmation Screen**
7. **Confirm Collection** → Card dispensed

---

## Implementation Notes

### During Authentication

**In `auth.py` or equivalent:**

```python
def verify_pin_and_check_temp(reg_number, submitted_pin):
    # Verify PIN against hash
    is_valid = verify_pin(reg_number, submitted_pin)

    if not is_valid:
        # Handle failure, increment counter, check lockout
        return False

    # PIN was correct — now check if it's temporary
    is_temp = get_is_temp_pin_flag(reg_number)

    if is_temp:
        # Force permanent PIN setup before collection
        return REQUIRES_PIN_SETUP
    else:
        # Proceed to collection confirmation
        return SUCCESS
```

### During Permanent PIN Setup

**In `auth.py` or equivalent:**

```python
def set_permanent_pin(reg_number, new_pin):
    # Hash the new PIN
    pin_hash = bcrypt.hashpw(new_pin.encode(), bcrypt.gensalt())

    # Update database
    DB.execute(
        "UPDATE authentication SET pin_hash = ?, is_temp_pin = FALSE WHERE registration_number = ?",
        (pin_hash, reg_number)
    )
```

### Database Cleanup (Phase 2, Task 2.5)

When deleting old collected card records older than 120 days, also delete their associated authentication rows:

```python
def cleanup_old_records():
    # Delete authentication records for collected cards older than 120 days
    DB.execute(
        """
        DELETE FROM authentication
        WHERE registration_number IN (
            SELECT registration_number FROM cards
            WHERE card_status = 'collected'
            AND created_at < datetime('now', '-120 days')
        )
        """
    )
```

---

## Table Summary

| Table | Purpose | Key Columns |
| --- | --- | --- |
| `students` | Student records | `registration_number` (PK), `first_name`, `surname`, `email`, `phone_number`, `programme`, `year_of_study`, `date_of_birth`, `national_id_number`, `faculty`, `registration_status` |
| `cards` | Track individual ID cards | `card_id` (PK), `registration_number` (FK), `slot_index`, `card_status`, `batch_id`, `created_at`, `updated_at` |
| `authentication` | PIN/OTP credentials & security | `auth_id` (PK), `registration_number` (FK), `otp_hash`, `otp_expiry`, `pin_hash`, **`is_temp_pin`**, `failed_otp_attempts`, `failed_pin_attempts`, `lockout_expiry` |
| `audit_log` | Immutable audit trail | `log_id` (PK), `timestamp`, `registration_number`, `event_type`, `failure_type`, `session_id` |
| `batches` | Staff loading sessions | `batch_id` (PK), `staff_id`, `scan_timestamp`, `total_cards`, `stored_count`, `rejected_count`, `sms_sent_count` |

---

## Schema Initialization

The `init_db.py` script reads `schema.sql` and creates all tables with proper constraints and indices on first run. The database is immutable after creation — all modifications happen through application code.

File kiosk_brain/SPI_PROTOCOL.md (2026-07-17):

# SPI Communication Protocol: Raspberry Pi 5 ↔ Arduino Mega 2560

## Overview

Defines the ASCII-level protocol for Raspberry Pi 5 to Arduino Mega 2560 communication over the SPI bus at 100 kHz.
Every transmission is exactly 2 characters (2 bytes) of ASCII data, terminated by a null character in the receiver buffer. No checksum bytes or complex frame overhead is used in this prototype.

---

## Physical Interface

- **Raspberry Pi 5 (Master)**:
  - Bus: SPI0 (GPIO 11 = SCK, GPIO 10 = MOSI, GPIO 9 = MISO, GPIO 8 = CE0)
  - Speed: 100 kHz (configured in `spi_master.py`)
  - Mode: SPI Mode 0 (CPOL=0, CPHA=0)
- **Arduino Mega 2560 (Slave)**:
  - Pins: SS (53), MOSI (51), MISO (50), SCK (52)
  - Common Ground: A shared common ground reference point must be established between both boards.
  - Logic Level Shift: A logic level shifter must be used on the MISO line (5V to 3.3V) to protect the Pi.

---

## Transmission Frame Format

Commands sent by the Raspberry Pi are 2-character ASCII strings. The Arduino Mega reads the 2 bytes, terminates them as a string, and processes the corresponding routing routine.

```text
Byte 0: Command Group / Transaction Prefix ('0', '1', '2', 'F')
Byte 1: Target slot index ('0', '1', '2') or command identifier ('0', 'F')
```

---

## Command Reference Table

The following status and command frames are sent by the Raspberry Pi `spi_master.py`:

| ASCII Frame | Transaction Type | Action / Target Meaning |
| --- | --- | --- |
| `"10"` | Ingestion (OCR)  | Route Compartment A to Entrance (0°) and trigger servo release |
| `"11"` | Ingestion (OCR)  | Route Compartment B to Entrance (120°) and trigger servo release |
| `"12"` | Ingestion (OCR)  | Route Compartment C to Entrance (240°) and trigger servo release |
| `"00"` | Ingestion (OCR)  | OCR Error/Failure: Route Compartment C to Entrance (240°) |
| `"20"` | Collection (UI)  | Route Compartment A to Exit (180°) and await pickup |
| `"21"` | Collection (UI)  | Route Compartment B to Exit (300°) and await pickup |
| `"FF"` | Collection (UI)  | UI Transaction Failure / Cancelled |

---

## Error and Status Handling

- **Invalid Command**: The Arduino Mega logs "Unknown SPI Frame" via its serial monitor on baud 115200 if the received 2-byte frame does not match any known commands.
- **SS Pin Synchronization**: The Mega's software buffer index resets whenever the Chip Select (SS) line goes HIGH (signaling that the Pi has released the SPI bus), which automatically maintains word synchronization.

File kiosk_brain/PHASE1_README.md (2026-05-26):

# Phase 1: OCR Pipeline — Implementation Guide

## Overview
Phase 1 implements a 3-stage OpenCV + Tesseract pipeline to extract student registration numbers from UDSM ID cards. This document guides you through each stage of implementation and testing.

**Current Focus:** Phase 1.1 — Camera Capture & Lighting Validation  
**Target Completion:** >90% accuracy on first-attempt extraction  
**Estimated Duration:** 13.5 hours total

### SSH Mode & Headless Operation
This project runs in **SSH headless mode** (no attached display). The camera module (`ocr.py`) automatically detects SSH mode by checking if the `DISPLAY` environment variable is set:

```python
DISPLAY_AVAILABLE = os.getenv("DISPLAY") is not None
SSH_MODE = not DISPLAY_AVAILABLE
```

**Implication:** GUI-based tools (like `calibrate_roi.py`) cannot display windows over SSH. **Workaround:**
1. Capture frames and save them to `tests/fixtures/ocr_frames/`
2. Download frames to your Ubuntu PC
3. View and analyze frames in VS Code or image viewer
4. Manually enter calibration coordinates into `config.py` (or use SSH port forwarding with X11 if your Ubuntu has a display)

---

## Phase 1.1: Camera Capture & Lighting Validation (2.5 hrs)

### Objective
Verify that the Pi Camera is functional, properly positioned, and receiving adequate lighting to capture readable registration numbers.

### Prerequisites
- ✅ Pi Camera physically connected to CSI port (v2 or v3)
- ✅ Camera interface enabled in `raspi-config`
- ✅ `picamera` library installed for v2 (or `picamera2` for v3, or OpenCV fallback available)
- ✅ SSH access configured (for headless operation from Ubuntu PC)

### Tasks

#### Task 1.1.1 — Verify Camera is Functional

**Status:** ✅ IMPLEMENTED

Verifies the Pi Camera can capture frames at the target resolution (2560×1440 QHD).

**Run:**
```bash
cd kiosk_brain
python tests/test_camera.py
```

**What it does:**
1. Initializes the camera (picamera2 for v3, picamera for v2, or OpenCV fallback)
2. Captures 3 sequential frames with 500ms delay between captures
3. Saves frames to `tests/fixtures/ocr_frames/frame_YYYYMMDD_HHMMSS_mmm.jpg`
4. Reports frame dimensions, data type, and file sizes
5. Prints detailed diagnostics for troubleshooting

**Acceptance Criteria:**
- ✓ All 3 frames captured without errors
- ✓ Frames saved to `tests/fixtures/ocr_frames/` directory
- ✓ Frame dimensions are exactly 2560×1440 QHD
- ✓ Frame data type is uint8 (8-bit per channel)
- ✓ Each frame is ~450–500 KB (JPEG compressed)

**Expected Output:**
```
======================================================================
TASK 1.1.1 - CAMERA VERIFICATION TEST
======================================================================
Testing Pi Camera capture at (1280, 720)

[1/4] Initializing camera...
✓ Camera initialized successfully

[2/4] Capturing 3 test frames (500ms delay between captures)...
✓ Frame captured #1: shape=(720, 1280, 3), dtype=uint8
✓ Frame captured #2: shape=(720, 1280, 3), dtype=uint8
✓ Frame captured #3: shape=(720, 1280, 3), dtype=uint8
✓ Successfully captured 3 frames

[3/4] Analyzing captured frames...
   Frame 1:
      Shape (HxWxC): (720, 1280, 3)
      Data type: uint8
      Size: 0.35 MB
      ✓ Resolution correct: 1280x720
   ...

[4/4] Verifying saved frame files...
✓ Saved 3 frame files to tests/fixtures/ocr_frames/
   - frame_20260525_143022_456.jpg (342.1 KB)
   - frame_20260525_143022_961.jpg (338.5 KB)
   - frame_20260525_143022_1467.jpg (340.2 KB)

======================================================================
✅ SUCCESS: TASK 1.1.1 PASSED
======================================================================
```

**Troubleshooting:**

| Issue | Cause | Solution |
|---|---|---|
| "Camera not ready for capture" | Camera not initialized | Check: `raspi-config` → Interface Options → Camera enabled? |
| ImportError: picamera2 | Library not installed | `pip install picamera2` (Pi only) |
| cv2.VideoCapture.read() failed | Camera not accessible | Check USB/CSI connection; restart Pi; try `fswebcam -r 1280x720` |
| Frames are blurry | Camera out of focus | Adjust camera lens (manual focus) or move camera closer/farther |
| Frames are very dark | Insufficient lighting | Natural light may not be adequate; consider adding LED (Task 1.1.3) |

---

#### Task 1.1.2 — Design Capture Workflow

**Status:** ✅ IMPLEMENTED (in CameraCapture class)

Defines how frames will be captured during the card ingestion process (staff batch loading).

**Configuration in `config.py`:**
```python
OCR_FRAME_RESOLUTION = (1280, 720)  # (width, height)
OCR_FRAME_RATE = 30  # fps - target frame rate
```

**Workflow Decisions Made:**
1. **Resolution:** 2560×1440 QHD (16:9 aspect ratio)
   - ✓ 4× more pixels for text clarity
   - ✓ Better OCR accuracy on small text
   - ✓ Capture time ~600ms per frame (acceptable for batch operation)
   
2. **Capture Mode:** Event-triggered (during staff batch loading)
   - ✓ Not continuous (saves CPU, power)
   - ✓ Triggered when card detected at Conveyor 1 scan station
   - ✓ Single capture per card (not multi-frame averaging yet)
   
3. **Frame Rate:** 30 fps target
   - ✓ Real-time processing on Pi 5
   - ✓ Sufficient for manual staff batch loading (~1 card every 2 seconds)

**Implementation Details:**
- CameraCapture class in `modules/ocr.py`
- Methods: `capture_frame()`, `capture_multiple_frames()`, `get_frame_info()`
- Supports both picamera2 (Pi) and OpenCV fallback (testing on desktop)
- Automatic frame storage to disk with timestamp filenames

---

#### Task 1.1.3 — Test Lighting Conditions

**Status:** ⏳ NEXT (Manual verification required)

Tests whether natural light is sufficient for OCR, or if an LED light source is needed.

**Procedure:**

1. **Inspect captured frames** (from Task 1.1.1)
   ```bash
   # View frames in ocr_frames/ directory
   file ocr_frames/*.jpg
   display ocr_frames/frame_*.jpg  # or open in any image viewer
   ```

2. **Check readability criteria:**
   - ✓ Can you easily read the registration number by eye?
   - ✓ Is the text sharp (not blurry)?
   - ✓ Is there glare or shadows obscuring the text?
   - ✓ Is the background uniform (no specular reflections)?

3. **Decision tree:**
   - **If text is clear and readable** → Natural light is adequate ✓
     - Proceed to Task 1.1.4
   - **If text is readable but dim** → Consider adding LED
     - Proceed with Task 1.1.4; add LED after calibration if accuracy < 90%
   - **If text is hard to read** → Add diffuse LED light source
     - Recommend: Warm white LED strip (5000–6500K) above scan station
     - Angle ~45° to minimize glare
     - Run test_camera.py again after adding light

**Acceptance Criteria:**
- ✓ Registration number is legible by human eye on at least 2 of 3 captured frames
- ✓ No severe glare or shadows on the registration number region
- ✓ Documented decision: "Natural light sufficient" or "Added LED light source"

---

#### Task 1.1.4 — Calibrate ROI Coordinates

**Status:** ✅ IMPLEMENTED (interactive tool ready)

Identifies the exact pixel coordinates of the registration number region on the ID card.

**Run:**
```bash
cd kiosk_brain
python tools/calibrate_roi.py
```

**What it does:**
1. Loads the latest frame from `ocr_frames/`
2. Displays the frame in a window
3. You click-and-drag to select the registration number region
4. Double-click to confirm
5. Coordinates are saved to `config.py` as `OCR_ROI_COORDINATES`

**Detailed Instructions:**

1. **Run the calibration tool:**
   ```bash
   python calibrate_roi.py
   ```

2. **When the frame window opens:**
   - Look for the registration number (left-center region)
   - Click at the **top-left corner** of the registration number
   - Drag to the **bottom-right corner**
   - Release the mouse button

3. **Verify the bounding box:**
   - A green rectangle appears showing your selection
   - Check that it tightly bounds the registration number
   - The instructions say "Double-click to confirm or click to restart"

4. **Confirm or restart:**
   - **To confirm:** Double-click anywhere on the frame
   - **To restart:** Single-click to select again

5. **Coordinates are saved:**
   ```python
   OCR_ROI_COORDINATES = (x1, y1, x2, y2)
   ```

**Acceptance Criteria:**
- ✓ ROI width is 100–200 pixels
- ✓ ROI tightly bounds the registration number area
- ✓ ROI coordinates saved to `config.py`
- ✓ Verified by running: `python show_roi.py`

**Example:**
```bash
$ python calibrate_roi.py

======================================================================
TASK 1.1.4 - ROI CALIBRATION
======================================================================

...

======================================================================
✅ ROI SELECTION COMPLETE
======================================================================

Selected coordinates: (150, 250, 400, 280)
ROI dimensions: 250px × 30px

✓ ROI width acceptable (100–200px)

Saving to config.py...
✓ config.py updated

Next steps:
  1. Verify ROI visually by running: python show_roi.py
  2. If satisfied, proceed to Task 1.2 (Image Preprocessing)
```

**Verification:**
```bash
$ python tools/show_roi.py

Loading frame: frame_20260525_143022_456.jpg
Displayed frame with ROI bounding box (green rectangle)
Press any key to close

✓ Visualization closed
```

---

## Phase 1.2: Image Preprocessing Pipeline (5 hrs)

### Overview
Prepares raw camera frames for OCR:
- Grayscale conversion
- Adaptive thresholding (binarization)
- Perspective correction (deskewing)
- ROI extraction
- Filtering & sharpening

**Status:** ⏳ NOT STARTED (blocked on Phase 1.1)

**Expected Implementation:**
```python
def preprocess_frame(frame: np.ndarray, roi_coordinates: Tuple[int, int, int, int]) -> Tuple[np.ndarray, np.ndarray]:
    """
    Returns:
        (preprocessed_frame, roi_crop)
    """
    # 1. Convert to grayscale
    # 2. Apply adaptive threshold
    # 3. Deskew (perspective correction)
    # 4. Crop to ROI
    # 5. Apply blur + sharpening
    # 6. Return both full preprocessed frame and ROI crop
```

---

## Phase 1.3: Tesseract OCR Integration (2 hrs)

### Overview
Extracts text from preprocessed frames using Tesseract.

**Status:** ⏳ NOT STARTED

**Expected Implementation:**
```python
def extract_registration_number(frame: np.ndarray, min_confidence: float = 0.85) -> Dict:
    """
    Returns:
        {
            "success": bool,
            "registration_number": str | None,
            "confidence": float,
            "error": str | None
        }
    """
```

---

## Phase 1.4: Validation & Reject Logic (1.5 hrs)

### Overview
Validates extracted text against UDSM registration number format.

**Status:** ✅ IMPLEMENTED (partially)

**Format Regex:**
```python
OCR_REGISTRATION_FORMAT_REGEX = r"^20\d{2}-04-\d{5}$"
# Matches: 2022-04-09050, 2023-04-12345
# Rejects: 2022-05-09050, 22-04-09050
```

---

## Phase 1.5: Accuracy Testing (2.5 hrs)

### Overview
Tests the complete pipeline against 20+ real UDSM ID cards to achieve ≥90% accuracy target.

**Status:** ⏳ NOT STARTED (blocked on Phases 1.2–1.4)

---

## File Structure

```
kiosk_brain/
├── modules/ocr.py                  # Core OCR module (CameraCapture class + functions)
├── config.py                        # OCR configuration constants
│
├── tests/                           # Test scripts & unit tests
│   ├── test_camera.py              # Task 1.1.1 verification script
│   ├── test_auth.py                # (existing) Auth testing
│   ├── test_ocr.py                 # OCR pipeline tests (1.2–1.5)
│   ├── test_spi.py                 # (existing) SPI testing
│   └── fixtures/                   # Test data & resources
│       └── ocr_frames/             # Captured test frames (generated)
│
├── tools/                          # Interactive CLI utilities
│   ├── calibrate_roi.py            # Task 1.1.4 ROI calibration tool
│   └── show_roi.py                 # ROI visualization script
│
└── PHASE1_README.md                # This file
```

---

## Running the Full Phase 1.1 Workflow

```bash
cd kiosk_brain

# Step 1: Verify camera
python tests/test_camera.py

# Step 2: Check captured frames visually
# - Open tests/fixtures/ocr_frames/*.jpg in image viewer
# - Verify registration number is readable
# - Note lighting conditions

# Step 3: Calibrate ROI
python tools/calibrate_roi.py

# Step 4: Verify ROI
python tools/show_roi.py

# Step 5: If satisfied
# - Proceed to Phase 1.2 (Image Preprocessing)
# - Or adjust camera angle/lighting and repeat Task 1.1.3
```

---

## Current Status

| Task | Status | Notes |
|---|---|---|
| 1.1.1 Verify camera | ✅ READY | `python test_camera.py` |
| 1.1.2 Design workflow | ✅ DONE | Resolution & frame rate configured |
| 1.1.3 Test lighting | ⏳ PENDING | Manual visual inspection required |
| 1.1.4 Calibrate ROI | ✅ READY | `python calibrate_roi.py` |
| 1.2 Preprocessing | ⏳ NOT STARTED | Blocked on 1.1 completion |
| 1.3 Tesseract OCR | ⏳ NOT STARTED | Blocked on 1.2 completion |
| 1.4 Validation | ⏳ PARTIAL | Regex implemented, decision logic stubbed |
| 1.5 Accuracy testing | ⏳ NOT STARTED | Blocked on 1.3 completion |

---

## Next Steps

1. **Immediately:** Run `python test_camera.py` to verify camera functionality
2. **After camera test:** Inspect frames in `ocr_frames/`; verify registration number is readable
3. **After visual inspection:** Run `python calibrate_roi.py` to calibrate ROI coordinates
4. **After calibration:** Proceed to Phase 1.2 (Image Preprocessing) ← Next milestone

---

## Troubleshooting

**Camera not detected:**
- Check physical CSI connection
- Run: `vcgencmd get_camera`
- Enable in: `sudo raspi-config` → Interface Options → Camera

**Frames not found error:**
- Run `python tests/test_camera.py` first to capture frames
- Frames are saved to `tests/fixtures/ocr_frames/`

**Frames are blurry:**
- Adjust Pi Camera lens (manual focus)
- Move camera closer/farther from card
- Verify card is held flat under camera

**Frames are dark:**
- Natural light may not be sufficient
- Add LED light source (warm white, 5000–6500K)
- Angle light at ~45° to minimize glare

**ROI calibration not saving:**
- Check file permissions: `ls -l config.py`
- Ensure `config.py` is writable: `chmod 644 config.py`

---

## Questions or Issues?

- Check the BUILD.md for overall project progress
- Review the OCR module documentation: `modules/ocr.py` docstring
- Test logs are printed to console; capture output with: `python test_camera.py 2>&1 | tee test_camera.log`

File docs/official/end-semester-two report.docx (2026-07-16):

UNIVERSITY OF DAR ES SALAAM

COLLEGE OF INFORMATION AND COMMUNICATION TECHNOLOGY

DEPARTMENT OF ELECTRONICS AND TELECOMMUNICATIONS ENGINEERING

FINAL YEAR REPORT END SEMESTER TWO

PROJECT TITLE: DESIGN AND IMPLEMENTATION OF AN AUTOMATIC ID CARD ISSUANCE SYSTEM

Student’s Name: Samuel Dan Musyani

Registration Number: 2022-04-09050

Supervisor’s Name: Dr. Hashimu Iddi

# ABSTRACT

Manual student ID card distribution at University scale suffers from operational inefficiencies such as extended queue times, narrow service windows confined only to working hours, and a significant administrative burden on staff. This project addresses these constraints through an automated self service kiosk system that retrieves and dispenses pre-printed student identification cards on demand.

The implementation comprises a distributed two tier architecture: a Raspberry Pi 5 serving as a high – level controller for user interface, computer vision processing, authentication logic and database management; and an Arduino Mega 2560 operating as a real time slave controller for mechanical actuation. Communication between controllers occurs via SPI protocol using a two-byte ASCII frame format. The software pipeline includes an optical character recognition (OCR) module for card registration number extraction, two – factor authentication using SMS delivered one time passwords (OTP) with BRIQ Solutions for SMS gateway delivery. Mechanical actuation employs a carousel based circular storage chamber with servo motor control for card positioning and ejection.

The system demonstrates functional OCR detection with validation against institutional registration number formats, complete authentication workflows with bcrypt secured credential storage and configurable lockout policies, and a fully implemented SQLite database schema supporting audit complicance. The software and hardware integration delivers a scalable, auditable ID card distribution system suitable for deployment across University environments.

# TABLE OF CONTENTS

# LIST OF TABLES

# LIST OF FIGURES

# LIST OF ABBREVIATIONS

ABBREVIATIONS | LONG FORM
2FA | 2-Factor Authentication
API | Application Program Interface
CAD | Computer Aided Design
CLK | Clock
CS | Chip Select
DB | Database
GB | Gigabyte
ID | Identification
IoT | Internet of Things
MISO | Master In Slave Out
MOSI | Master Out Slave In
OCR | Optical Character Recognition
OS | Operating System
OTP | One Time Password
PVC | Poly-Vinyl Chloride
PWM | Pulse-Width Modulation
RAM | Random Access Memory
SMS | Short Message Service
SPI | Serial Peripheral Interface
Wi-Fi | Wireless Fidelity

# CHAPTER ONE: INTRODUCTION

## 1.1 BACKGROUND

Universities commonly issue student ID cards that serve as proof of registration and campus identification for various services to students. At the University of Dar es Salaam, the card collection process, which occurs immediately after students have completed registration, involves queuing at the responsible office for collection. However, for a high volume of students, this results in long waiting times, narrow service windows (only operating during working hours), and staff exhaustion.

Therefore, the project aims to develop a prototype of an Automated ID Card Issuance System that sorts and gives out pre-printed ID cards to students on demand at all times. The system integrates a microcontroller that controls actuators in real-time, a single-board computer that performs computer vision (for ID identification), student’s identity authentication, logging of various activities, and back-end integration. The intended solution aims to reduce distribution time while ensuring secure ID card distribution as it is.

## 1.2 PROBLEM STATEMENT

The current student ID card issuance process at University of Dar es Salaam involves a waiting period of approximately one week after registration due to delayed card availability in the individual’s college. After release, the card collection also requires students to queue and sort a bunch of ID cards. So, for a high volume of students, the staff responsible suffers significant work strain. On top of that, fixed hours also hinder the sorting capacity of students' issuance per time. As a result, card issuance for registered students takes up to several days, which may bring inconvenience to students.

## 1.3 MAIN OBJECTIVE

Design and implementation of an Automated ID Card Issuance System for pre-printed student ID cards with secure authentication and audit logging while serving students at all times.

## 1.4 SPECIFIC OBJECTIVE

1. To implement a reliable control system for actuators using a microcontroller capable of selecting and dispensing a single card from a pile of cards in a stored compartment.
2. To implement a computer board application that gives out authentication OTPs, verifies the student’s set pin, receives the user registration data, verifies it against a database, and communicates the command to the microcontroller.
3. To implement robust logging of each transaction details in database for auditing and debugging.
4. To implement security policy that uses SMS-delivered OTPs as authentication mechanism, and also enforce measures to deal with invalid attempts and communication to system admin.
5. To evaluate system performance using metrics such as average card retrieval time, authentication success, error handling and dispense rate.
6. To produce a formal report involving design of the prototype at various milestones.

## 1.5 SIGNIFICANCE OF STUDY

- Operational efficiency: the proposed system reduces long queues and waiting times by allowing students to retrieve ID cards on demand without any staff intervention.
- Reduced administrative burden: the system performs automation which replaces the repetitive tasks done by a university staff allowing them to focus on higher level tasks.
- Scalability, accessibility and replicability: Although the proposed system is implemented as a prototype for UDSM, the system can be adopted by other institutions such as banks for card applications. Also, access to students retrieving their ID cards beyond standard normal working hours.
- Academic contribution: the project demonstrates practical application of embedded systems, back-end software and other mechanical design theory and automation studied as theory in various academic year(s).

## 1.6 SCOPE AND LIMITATIONS

This project focuses on the design and implementation of an Automated ID Card Issuance System which integrates the software part (back-end, user interaction and computer vision verification) and hardware part with microcontroller and actuators for card sorting and dispensing the said card. Therefore, the prototype does not implement on-device printing of the PVC cards, mobile application or payment gateway.

The system intends to use a mock database for testing unless institutional access is granted.

# CHAPTER TWO: LITERATURE REVIEW

In this chapter, various existing systems, projects and technologies related to the proposed project are reviewed. The purpose of the review is to understand different approaches, scope, limitations and gaps and hence, establish basis of the proposed project. Therefore, the following points gathered below feature ideas with similar concepts as the proposed project.

## 2.1 RELATED PROJECTS

- Automatic and Smart Vending systems: these are some self-service systems that provide mostly goods (foods) to users without much human intervention, mostly observed in supermarkets for snacks and beverages. These systems have two categories: non-IoT machines, which operate by giving physical cash to the machine, and IoT machines, which work with cashless payments and track the availability of stock, locations to satisfy customer preferences by using microcontrollers (Ratnasri & Sharmilan, 2021). Also, some vending systems apply image processing with deep learning to detect and categorize various target objects of interest in the image. These kinds of vending machines also implement a weight data acquisition part to increase the accuracy of target object detection (Xia, K., Fan, H., Huang, J., Wang, H., Ren, J., Jian, Q., & Wei, D).
- System architectures and control strategies: in most of the dispensing applications, generally a microcontroller is used with a communication module, mostly Wi-Fi, with a logic to directly manage actuator control, sensor inputs, safety interlocks, and communicate with the server or a computer for other complex tasks (Prasad, Kumar, Shriram, Prof. Dr. Mane, 2024).
- Authentication and security: this is one of the most critical part of the system that deals with sensitive items. In automated environments, combining multiple verification layers (e.g OTP, biometrics, card scanning) improves security. In ATM systems, work on authentication explores multi-factor approaches, integrating OTPs with biometric factors to reduce unauthorized access risk (Kibaya, Lubobya, 2024).
- Automated pharmaceutical dispensing systems: feature customer interaction stations with graphical interfaces, drug verification stations, pill counting, packaging stations, and controllers managing communication with external systems and databases.
- Intelligent vending machines with computer vision:AI vending machines use real-time computer vision registering item removals with roughly 99% recognition accuracy across product categories. Systems recognize customers using facial recognition, recommend products based on purchase history, accept multiple payment types, monitor stock remotely, and self-diagnose technical faults with alerts to operators.
- Automated Library book retrieval and return systems: Library management robots use ESP32 microcontrollers processing sensor data in real time, servo motors for robotic arms with grippers, and RFID readers confirming book identity before retrieval; users request books through mobile applications. Unattended book management systems employ PLC-controlled mechanical hands, gas cylinders for motion control, and RFID detection at retrieval windows; failed detection triggers reversal of book basket to temporary storage (J Kumar, Nanditha V, Pranav P, Sona S, Mary Alex, 2025).

## 2.2 RESEARCH GAP

From the related projects, the proposed system aims to cover the gap that despite an extensive research on vending and kiosk systems, limited number of projects addresses secure low-cost automated distribution of pre-printed identification cards particularly in University environments.

# CHAPTER THREE: METHODOLOGY

## 3.1 OVERVIEW

The Automatic ID Card Issuance System was developed using a prototype-based, modular approach. Nonetheless, the work was completed in a well defined order that began with issue identification, function definition, system division into smaller modules, development and testing of each module, and integration of the modules into a single prototype. This strategy made sense since the project integrates electronic control, mechanical movement, and software.

The user interface, computer vision, authentication, database, controller communication and motor control were treated as separate modules and then interconnected.

## 3.2 PROBLEM IDENTIFICATION AND REQUIREMENT

The first step was to analyze the current process of student ID card collection and identify its main weaknesses. Usually students have to wait until the cards get to their colleges and then queue at an office during working hours. This results in long wait times, congestion and repeated work for staff. This problem defined the system's requirements. The proposed kiosk needed to recognise pre-printed cards, link each card to the correct student, store the location of the card, inform the student, authenticate the person collecting it, release the correct card and record all important activity.

The scope of the project was limited to issuance of cards that were already printed. The card printing, the payment services and a mobile application were excluded. A mock university database was used during development because direct access to the official institutional database was not guaranteed.

## 3.3 SYSTEM’S MODULES

After the definition of the requirements, the system was divided in a high level control section and a low level control section. The top layer runs on a Raspberry Pi and takes care of the user interface, student verification, card-image processing, authentication, database access, notifications and logging of transactions. The low-level section is based on an Arduino Mega and is designed to control the motors and other physical components used to position and release cards.

This separation allows the Raspberry Pi to decide and the Arduino to perform time sensitive physical actions. The whole design was divided into card registration, card storage, student notification, authentication, card retrieval, database management, communication and audit logging. The modular design gave the opportunity to develop and correct one part without re-building the whole system.

## 3.4 CARD IDENTIFICATION, REGISTRATION AND STORAGE

On the staff side, the implementation starts when the pre-printed student cards are placed in the kiosk. A camera takes a photo of each card. The image is processed to find the card, adjust the rotation, and zoom on the part containing the registration number. Then optical character recognition is used to read the registration number as it is unique to each student. The number extracted is checked for the expected university format and checked on the mock university database.

If the record is valid, the system retrieves the basic information of the student and writes the card to an available location in the storage chamber. The relationship between the student and the card and its storage position is saved in the local database. Cards that cannot be read or verified are rejected or marked for staff attention. This process ensures that the kiosk knows which card belongs to each student and where it is stored.

## 3.5 STUDENT NOTIFICATION AND AUTHENTICATION

After successful registration of card, the system will generate the one-time password and send it to the student through SMS and email. A first-time user may also be given a temporary PIN. During collection, starting the process from the touchscreen the student enters the registration number.

The system checks the student is valid, a card is available, the card has not been previously collected and the account is not locked. The student then enters the one time password. The first-time user also confirms the temporary PIN and sets up a personal permanent PIN. The combination of registration number with a one-time password and PIN provides more than a single level of identity verification. Wrong attempts are limited in number and multiple failures lead to temporary lockout.

3.6 USER INTERFACE AND DATABASE IMPLEMENTATION

To help the student navigate the collection process, an interface was created. Welcome, registration number entry, one-time password entry, PIN creation or verification, waiting for card dispensing, and final confirmation are all displayed in the same order as the actual process. When a student record is unavailable, a card has already been collected, authentication information is inaccurate, or the account is locked, the user is notified via separate error screens.

The interface uses large controls that are appropriate for a small kiosk display and offers one task at a time. Student records, card locations, authentication details, collection status, batches, and audit events are all stored in a local database that supports the interface. The audit log and stored status are updated upon card collection.

## 3.7 HARDWARE CONTROL AND MECHANICAL PROTOTYPE

A circular card-storage chamber with indexed places is used in the physical design. Every position has a corresponding slot in the database. The Raspberry Pi locates the designated slot and issues an instruction to the Arduino Mega after a student has been verified. The motors that move the chamber and release the chosen card are controlled by the Arduino.

Basic movement and card-ejection motions were tested using servo motors. Before the entire dispensing mechanism was completed, the communication and motor-control concepts were tested because the hardware part was created as a prototype. The dispensing screen in the current software interface depicts the anticipated background mechanical movement.

## 3.8 INTEGRATION AND TESTING

The various modules were gradually integrated once they were operational. In order to verify the extracted registration numbers, the computer vision module was linked to the student database. After that, card records were connected to storage locations, and authentication credentials were sent via the notification module. While communication methods were ready to transmit card-selection commands to the Arduino, the user interface was linked to the database and authentication modules.

Card detection and registration-number extraction were tested using sample card images. Authentication, attempt limitations, and lockout behavior were tested using both valid and invalid one-time passwords and PINs. Database testing verified logging, card assignment, record insertion, and collection updates. The low-level controller's ability to receive commands and control actuators was validated by communication and servo tests.

# CHAPTER FOUR: SYSTEM DESIGN

This chapter reviews various procedures to design, build and evaluate the performance of the prototype. It covers system architecture, hardware and software selection together and security.

## 4.1 SYSTEM ARCHITECTURE

The system’s control architecture as shown in the Figure 4.1 below depicts are planned isolation of two controllers. The high-level controller will be used to control the user interface, network connectivity, 2FA for OTP and student’s pin, database access, computer vision verification, transaction logging, and command issuing to the real-time controller. Then, a real-time controller will be used to directly control the motor, safety monitoring (limit switches), status reporting, and mechanical card sorting and ejection.

The pre-printed cards will be organized in indexed storage sections, which will be mapped to existing barcodes on the ID cards. Local (mock) database will be used to replicate the University DB scheme, and testing will emulate that unless permission is granted to access the database (API).

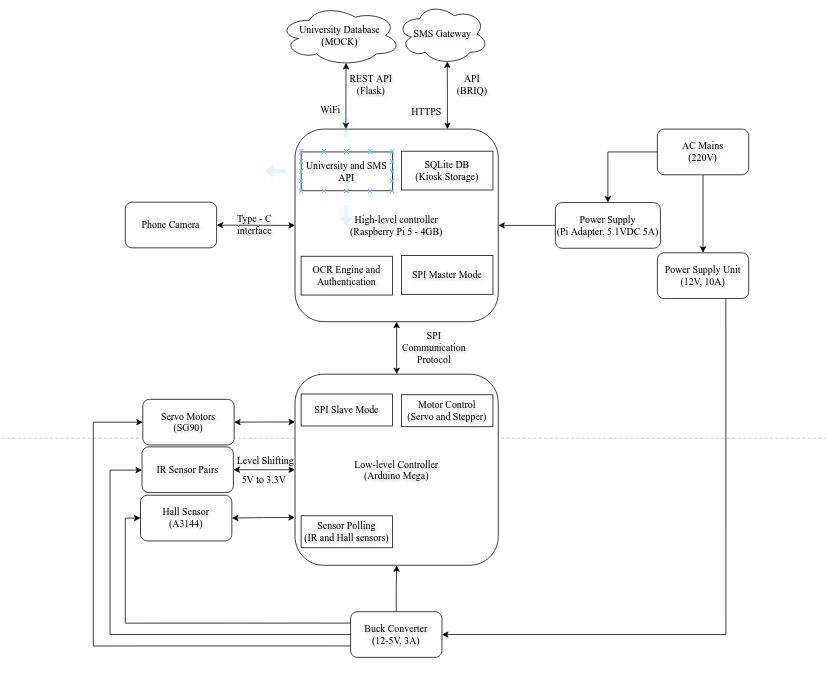
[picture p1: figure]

Figure 4.1: System’s block diagram

## 4.2 FUNCTIONAL WORKFLOW

The system’s workflow is divided into two distinct parts which are staff side and student side of the workflow. The two sides are clearly described in Figures 4.2 and 4.3 respectively, with the earlier explaining more on the first two phases, preload and notification phase, and the second figure elaborating on retrieval phase.

- Preload phase: responsible staff inserts a bunch of pre-printed cards into the dispenser, then the machine runs a routine scan and maps each card into a slot index in the dispenser DB. The high-level controller records the mapping with the individual card.
- Notification phase: when the cards are available, right after the routine scan, the high-level controller initiates triggering of SMS to particular students. The SMS includes an OTP valid for one retrieval attempt. If it is the particular student’s first time use, and extra different and temporary pin is sent via SMS for 2FA.
- Retrieval phase: First, students scan their expired card, and their information is shown on the screen (registration number, name, and degree programme), then an OTP prompt follows, as received from the SMS. Thereafter, the high-level controller validates the OTP and prompts for the student’s pin for extra layer of authentication. If it is the student’s first time use, after the prompt, the system gives a form to register a new custom pin which will be permanent for each individual.

After that, high-level sends the dispense command to the low-level controller to start the card dispensing process. The low-level microcontroller executes the motion to retrieve the card and verifies the card and its presence, and performs ejection while updating and returning the status to the high-level controller. Lastly, the high-level controller logs the transaction to the database as the audit logs.

- Security measures: after 3 invalid attempts for the same registration number within the same session, the system flags that particular number as locked for amount of time, notifies the system admin and returns to the home screen. In addition to that, in case of any physical tampering, the system alerts the admin and shuts down until manual admin reset is performed.

Below are the functional workflows featuring both student-side and staff-side access of the system:

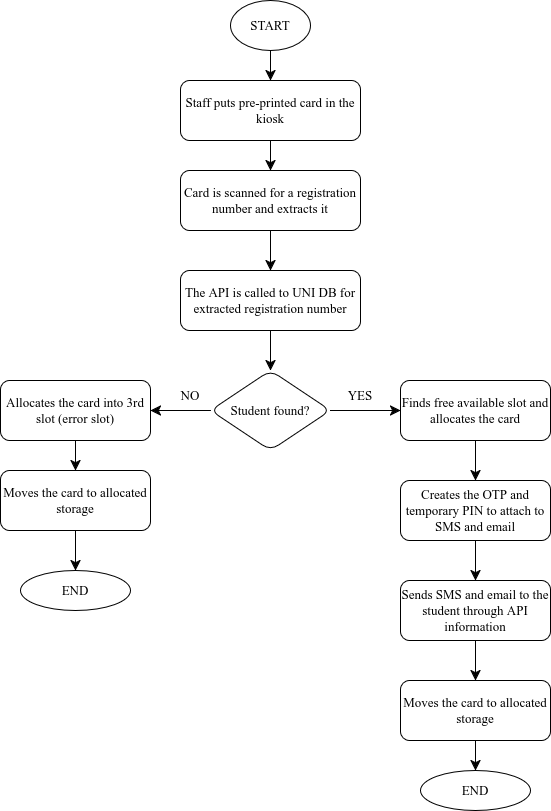
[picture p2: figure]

Figure 4.2: Staff-side functional workflow

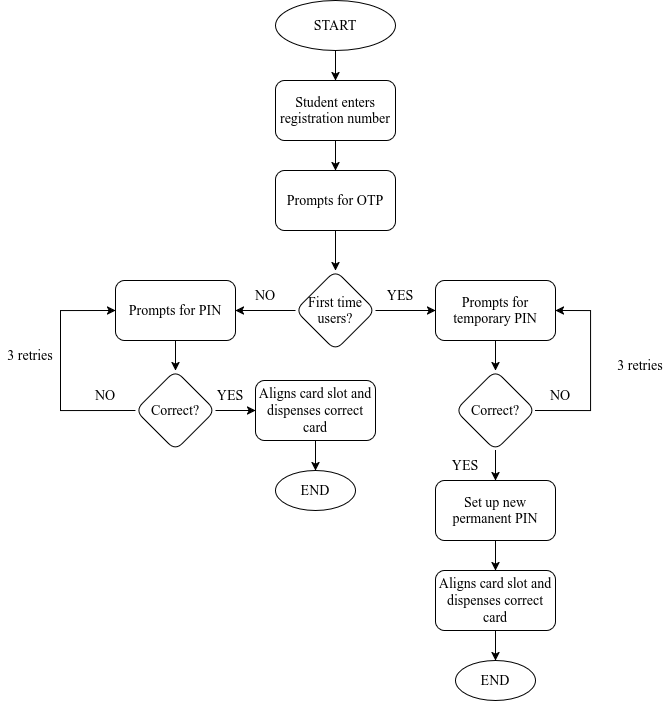
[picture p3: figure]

Figure 4.3: Student-side workflow

## 4.3 COMMUNICATION PROTOCOL

The communication protocol targeted between high-level controller and low-level controller is SPI, which has four wires (CLK, MOSI, MISO, CS) plus common ground, where Raspberry Pi is the master, with Arduino Mega as its slave. These communication signals from Raspberry Pi operate at 3.3V, while the signals from Arduino Mega operates at 5V. Since the Raspberry Pi is the master, signals at 3.3V were well – managed by the Mega counterpart. Arduino Mega does not communicate to Raspberry Pi, therefore only 3 wires used without level shifting of the voltage.

This communication protocol was selected due to high speed synchronous communication, full-duplex capability, simple hardware implementation and very reliable short distance communication.

Within this protocol, the commands (light messages) will be the ones to initiate various activities by the high-level controller through low-level controller done by the actuators.

## 4.4 SYSTEM CIRCUIT DESIGN AND ITS ARCHITECTURE

### 4.4.1 COMPONENTS USED

The hardware and software tools selected for this project were chosen based on their performance requirements, need for scalability and compatibility with each other. Since the project implementation is based on the integration of software and hardware linkage, Table 4.1 below explains the function of each hardware components along with its pictorial description:

Table 4.1: Hardware components

COMPONENTS | PICTURE | FUNCTIONALITY
Raspberry Pi 5 (4GB RAM) | | Hosts back-end application, OTP generation, database access, logging, computer vision and communication with low-level controller.
Arduino Mega | | Directly drives actuators, reads sensors and timing and safety logic.
Buck converter | | Converts 12VDC to a clean 5VDC for component usage.
Camera module V2 | | Visual images for card to support computer vision tasks.
Servo SG90 motor | | Move sorting mechanisms, control card selection and ejection.
Power Supply | | Conversion of 220VAC to suitable 12VDC for logic and control signalling.

On the software side of things, the components shown in Table 4.2 below were used to control the authentication process, database storage, and communication with hardware components. The following are the components:

Table 4.2: Software components

SOFTWARE COMPONENT | FUNCTIONALITY
Raspberry Pi OS | supporting system of the high-level controller.
Back-end Application | handles user input, authentication, interfaces with database, sends commands to low-level controller and manages error handling.
Database | stores students data and logs.
Computer Vision libraries | supports card insertion and ejection verification.
Low-level controller Firmware | executes motor control routines, reads sensors, implements communication and monitors safety.

### 4.4.2 HARDWARE CIRCUIT ARCHITECTURE

The hardware part of the Automated ID Card Issuance System is designed to support controlled mechanical actuation, stable power distribution and reliable communication between controllers. The circuit design was developed using Altium. The architecture design is divided into various design modules which include power regulation sub-system, Arduino Mega circuit control circuit, motor driver and actuation circuit and communication circuit interface.

### 4.4.3 POWER REGULATION

The system has two controllers that operate at 5V but with different current drawing capabilites. Raspberry Pi has peripherals to feed power and a hungry processor that needs up to 5A to work correctly, along with Arduino Mega that also uses the same voltage with only up to 2A with full working load. Therefore, a power circuit schematic as designed in Figure 4.4, provides the power supply for Arduino Mega and the hobby servo motors.

Due to that fact, the power concern was divided across each component individually. First, a dedicated Raspberry Pi adapter (Type – C) capable of converting 220VAC to 5VDC with 5A current rating to supply for the high – level controller. Secondly, a power supply that converts 220VAC to 12VDC was integrated with a buck converter that converts 12VDC to 5VDC with up to 3A current rating. This is designed to power the Arduino Mega and servo motors which uses 5V also.

The raw designs for buck converter using XL4015 are still presented below;

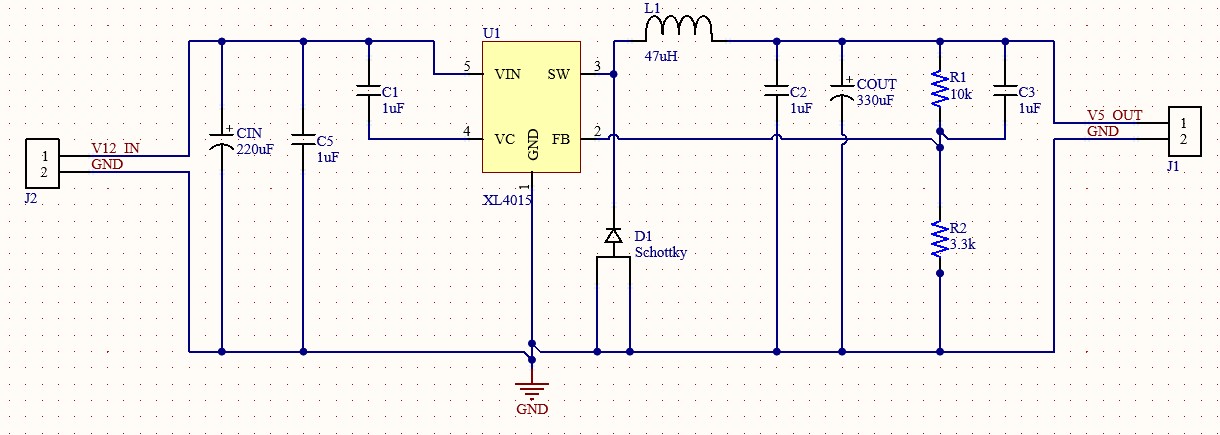
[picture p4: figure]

Figure 4.4: XL4015 buck converter

### 4.4.4 ARDUINO MEGA CORE CIRCUIT DESIGN

The Arduino Mega controller defines a real-time control of the system’s actuation and deterministic behaviours. Therefore, the core design includes: proper power supply connections with decoupling capacitors to reduce power supply variations and configuration of boot pins.

Arduino Mega programming interface platform to be used will be platfromIO, together with Visual Studio Code IDE as an environment to program a low-level microcontroller used. At this stage, those applications use a way of debugging that needs a hardware (chip or board) which is not yet implemented. On the next stage of this project, programming and implementation of the project will follow along.

### 4.4.5 ACTUATION DESIGN

The actuation sub-system is designed to control servo motors responsible for card transport and dispensing. The motor driver circuit is designed to interface with an MCU (Arduino Mega) through various control inputs and enable logic to drive the motors efficiently.

The motor power rail is efficiently extracted from a clean conversion from a XL4015 buck converter that gives out a constant of 5V (ideally) and up to 3A that gives a larger head room since servo motors only need up to 700mA to work efficiently. All reference points from the motors, MCU, converters and sensors are to be connected to one points.

## 4.5 COMPUTER VISION DESIGN INTEGRATION

The computer vision module’s aim is to detect and extract information from the inserted cards, either by the students or staffs. It performs OCR-based extraction of student’s registration number. The extracted data was chosen to be the registration number because it is unique for each student with no duplicate complications.

### 4.5.1 DESIGN DETAILS

The initial barcode-verification revealed some sensitivity to orientation variation and reflection hence OCR-based design was selected to reduce dependency on alignment of the card with lights and flexibility since text are relatively larger hence easier to identify than the barcodes.

### 4.5.2 PROCESSING PIPELINE

The proposed system design factored the PI camera capturing images of the cards, and the high-level controller processing them to extract the registration via OCR-based detection methods. As shown in the figure 4.5 below, the captured image goes through contour based detection for card edges, perspective correction for focus, ROI fixing and finally extraction:

Figure 4.5: Processing pipeline workflow

From the functional workflow, card detection is designed using edge detection and contour extraction techniques which are filtered according to geometric constraints such as minimum area and aspect ratio according the CR80 standard card size. Once a contour is detected, a perspective transformation is done to obtain a clear frontal view of the card to improve OCR detection stability.

The region of interest is determined by trial-and-error fixing according to the pixel cards. The format is (x, y, w, h) coordinates.

The extracted region is processed used OCR, and configured to prioritize numeric text recognition first. Then, after extraction by OCR, the expected format of registration number “YYYY-NN-XXXXX” is validated. Only the text that fits the description of format is considered as success.

## 4.6 BACK-END AUTHENTICATION DESIGN

The back-end system is designed to manage identity validation, authentication control and system logging for audits. Therefore, it acts as a bridge between the computer vision results and the low-level controller activities. If the authentication goes wrong, low-level controller cannot perform any mechanical activity. The sub-system performs three important services:

- Student verification service
- OTP Authentication service
- Audit logging service.

After a successful extraction of the registration number from computer vision processes, the back-end verifies the number against the University database and fetches information about the particular student and stores the registration number to the local system’s database. Only valid and active records are passed to authentication.

The main authentication mechanism is based on a One-Time Password (OTP) model. Each OTP produced is designed according to standard security principles:

- Randomized OTP generation
- Secure storage using hashing
- Time-limited validity
- Restricted number of attempts.

The OTP delivered to the student using a SMS gateway. During retrieval, the student inputs the received OTP through the user interface designed. Back-end then compares the hashed input against the stored and logs the action in either case, failure or success. The logging design ensures accountability and traceability.

## 4.6 MECHANICAL DESIGN

As the system requires a staff to load a pile of cards into a machine, and it sorts out each card according to the information and stores it, here is the design of it. The card sorting and storage system, will be a combination of stepper motor and a circular bin calculated with each slot to an assigned mapped number stored in the system’s database (Halac et al, 2025). If the card is needed, the bin is rotated by the servo motor up to the calculated position and a card is taken/ejected from the bin.

## 4.7 PROJECT SCHEDULE

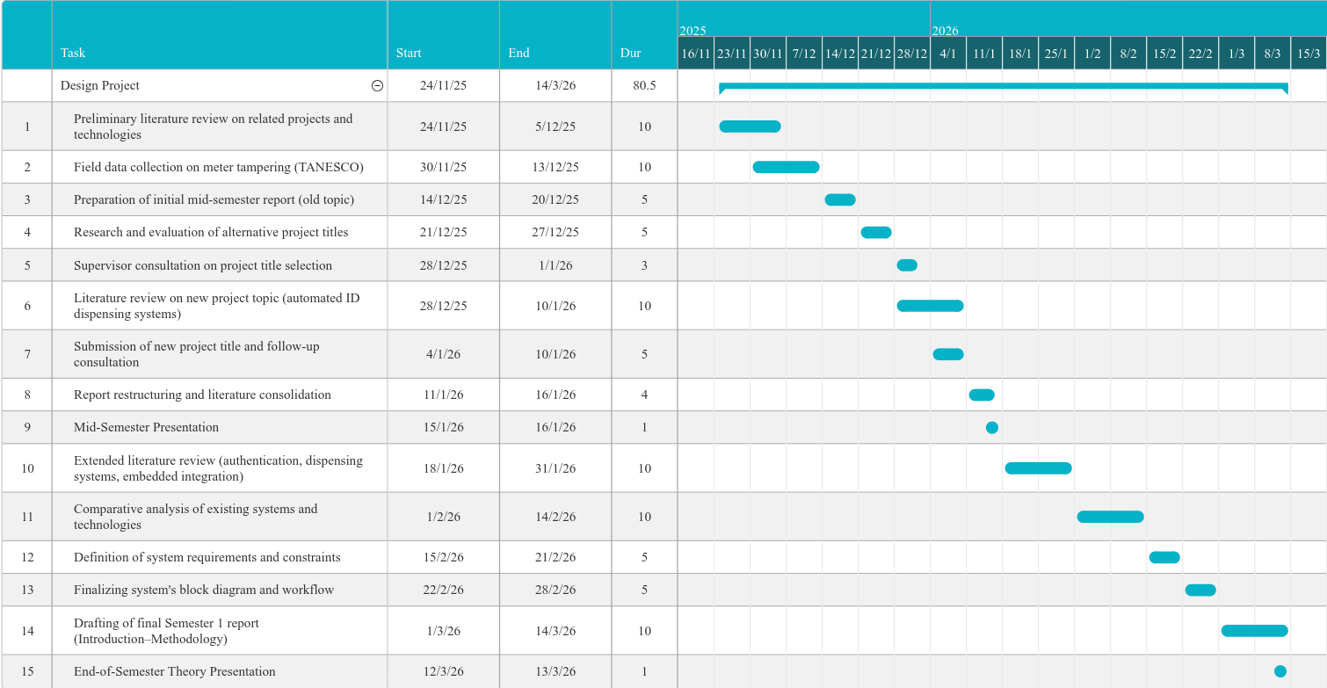
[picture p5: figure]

For first semester, the following Gantt chart shows various activities planned for proposed system:

Figure 4.6: Semester 1 activity plan (Gantt Chart)

For second semester, the following Gantt chart shows various activities planned for proposed system:

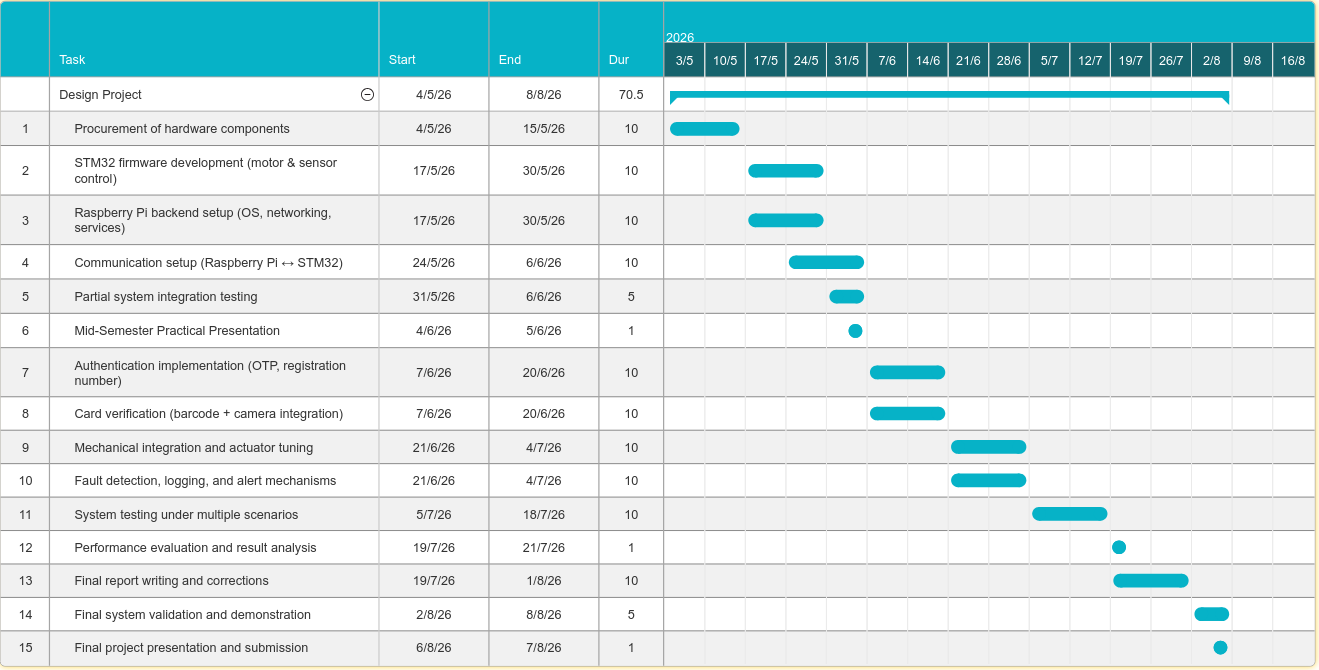
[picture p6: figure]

Figure 4.7: Semester 2 activity plan (Gantt Chart)

## 4.8 PROJECT BUDGET

As per logistics from local shops and imported components from AliExpress, Table 4.3 shows each component with their prices and an estimate on all the budget of the project.

Table 4.3: Project Budget

COMPONENT | ESTIMATED COST (TSh)
Raspberry Pi 5 (4GB) | 290,000
Low-level controller (Arduino Mega) | 60,000
Raspberry Pi Camera | 67,000
Actuators (Motors and their drivers) | 65,000
Sensors | 25,000
Enclosure and miscallenous components | 70,000
Power Supply | 13,000
Interfacing modules | 30,000
Perfboards and soldering equipments | 55,000
Minor repairs | 23,500
TOTAL | 563,500

# CHAPTER FIVE: SOFTWARE IMPLEMENTATION

This chapter depicts a complete implementation done (software) for the Automated ID Card Issuance System. The software parts involve the computer vision module for OCR detection and text extraction, authentication and SMS gateway configuration and user interface integration and transmission. This part of software will communicate with the hardware part which is in development for actual card sorting and ejection.

## 5.1 RASPBERRY PI APPLICATION

This sub-system implementation was done in a controlled Raspberry Pi OS. The focus on this was development and testing of the computer vision module and back-end authentication system together with the whole pipeline of these.

In the said raspberry Pi OS, other implementation environment and virtual environments included: python programming language, Open-CV library for image processing, Tesseract OCR engine for OCR detection, Fast API framework for back-end services and SQLite/PostgreSQL database for student records. Virtual environments were used to isolate system packages from the system’s.

### 5.1.1 COMPUTER VISION MODULE

Implementations for computer vision module was done as follows:

- Image capturing was done by a phone camera, transferred and stored in the raspberry Pi memory for processing. This is done as a placeholder for a Pi camera V2 module which is yet to be delivered in the country.
- Card detection and perspective correction, as shown in figure 5.1 and 5.2 below, contour-based detection was implemented to identify quadrilateral shapes (card shape) and the smoothing using gaussian thresholding (adaptive) was applied to improve OCR consistency by reducing distortions. Below are the results of card detection, green lines show verification:

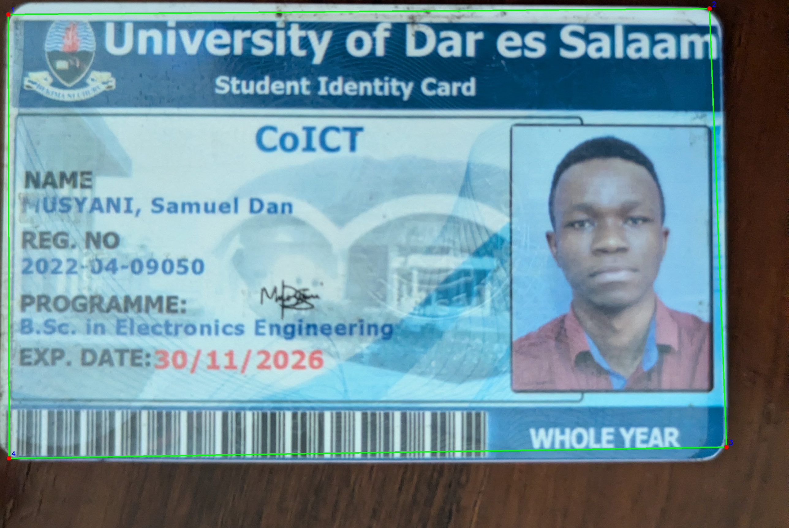
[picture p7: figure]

Figure 5.1: Sample card detected (green line shows detection)

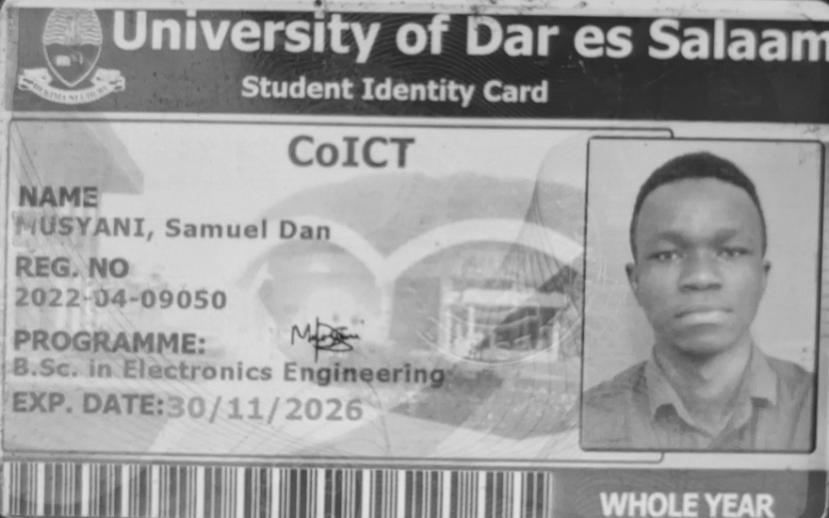
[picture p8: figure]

Figure 5.2: Processed grayscale sample image

- Pixel – based ROI localization, a known localized region of a standard CR-80 card was measured and calculated to attain the exact area where the registration number is located. So, with a corrected image and thresholded sample, clear characters can be extracted from a concentrated region.

So, for a pre-ocr settings for the CR-80 card was measured through trial-and-error method and the optimum settings as shown in figure 5.3 below with height, width and the coordinate (x, y) position of the region of interest with the outputs of the settings as shown in Figure 5.4 were as:

Figure 5.3: ROI settings for OCR

From the settings , there were outputs of regions of interest were observed for orignal, grayscale and threshold picture as to be shown below:

Figure 5.4: Previews of ROI outputs

- OCR extraction, validation and performance analysis, Tesseract OCR was used with prioritization of numeric recognition and validation of the extracted text against the institutional format. In addition to that, figure 5.5 shows processing time and success message that were extracted and logged into the system. The configuration settings for this are, English language, with single uniform text block (PSM 7), whitelist of alphanumeric characters only excluding the special symbols (Hyphen) in registration numbers.

Figure 5.5: Text extraction and processing performances

### 5.1.2 USER INTERFACE

From the success part of the computer vision module, here comes the user interface responsible for interaction between the machine and the student in need of the card, communication with the database for authentication and validation of information and access validity together with hardware integration for physical activities such that card sorting and ejection. The UI is designed for a 5” touchscreen (TFT – Display) which will be connected directly to the raspberry Pi as a high level controller. So, the following are the screens and various transitions and conditions required:

- Idle welcome screen as in figure 5.6, this is the one that is displayed on the screen as long as the system is ON. This shows that the system is ready for student’s interaction.

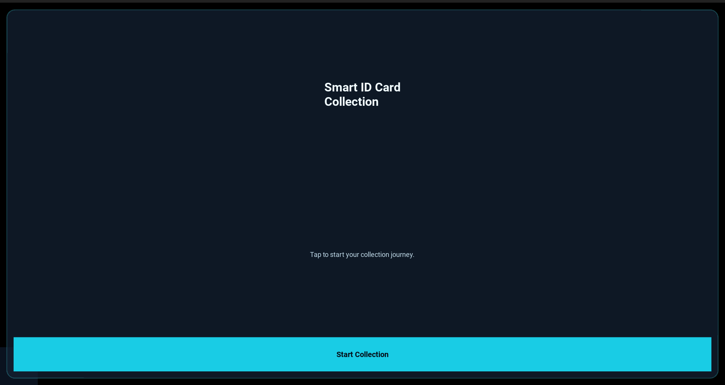
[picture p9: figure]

Figure 5.6: Idle UI screen for card kiosk

If a student presses the start collection button, it will transit to the next screen (registration entry screen) which prompts the student for his/her registration number.

- In figure 5.7, 5.8 and 5.9 respectively, registration number entry screen prompts the student to enter his/her registration number to which it is wired to the kiosk database. If should authenticate the student availability in the database. It checks for conditions such as if a student is not found, a card is already collected,

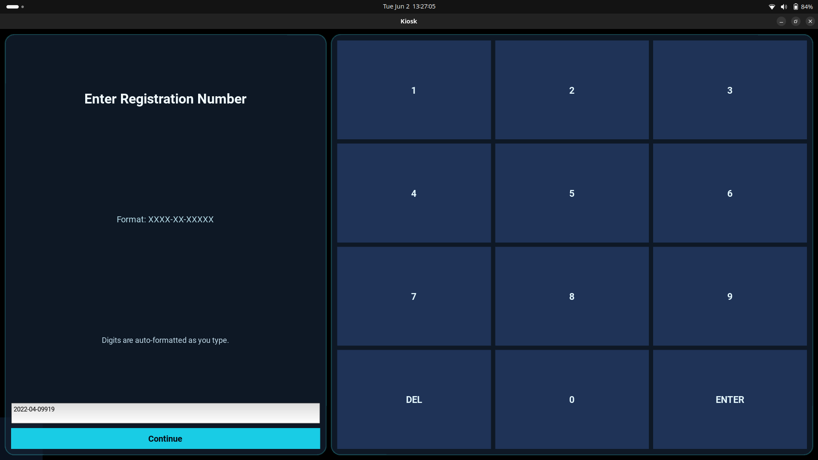
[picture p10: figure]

Figure 5.7: Initial registration number screen

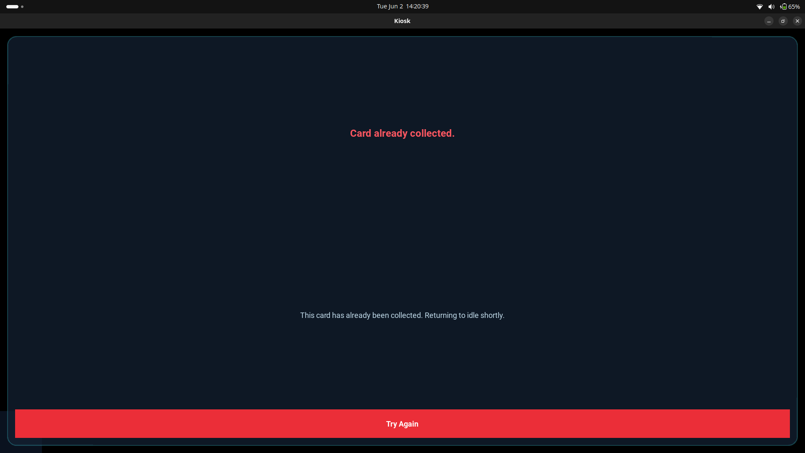
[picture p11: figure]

Figure 5.8: Registration entry screen for a repeated card

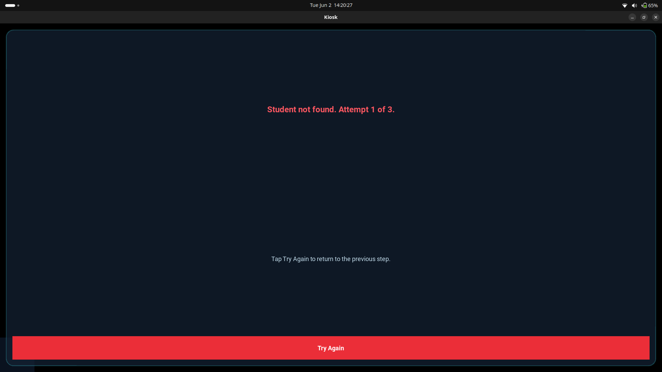
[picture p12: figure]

Figure 5.9: Registration entry screen for unavailable card

- OTP entry screen, student is required to enter a one time password as sent to the his/her email and phone number together as shown in figure 5.10. In figure 5.11 and 5.12 respectively, this screen validates the OTP and if correct, then the system transits to temporary PIN entry screen. If not, it warns the student and gives a maximum of three tries before the a lockout of the specific registration number.

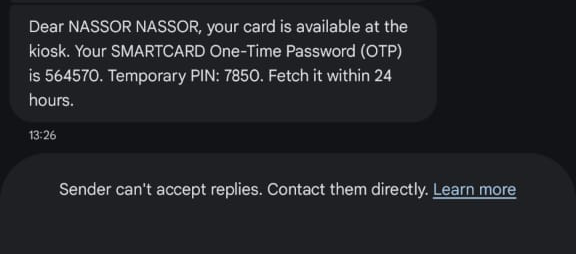
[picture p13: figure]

Figure 5.10: SMS message sent to sample student

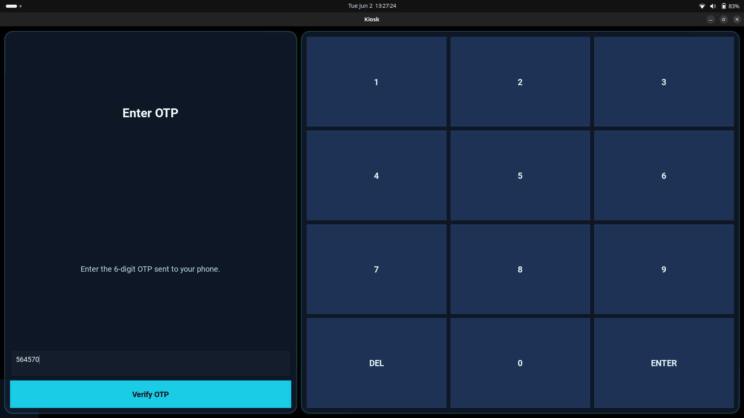
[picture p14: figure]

Figure 5.11: OTP initial screen

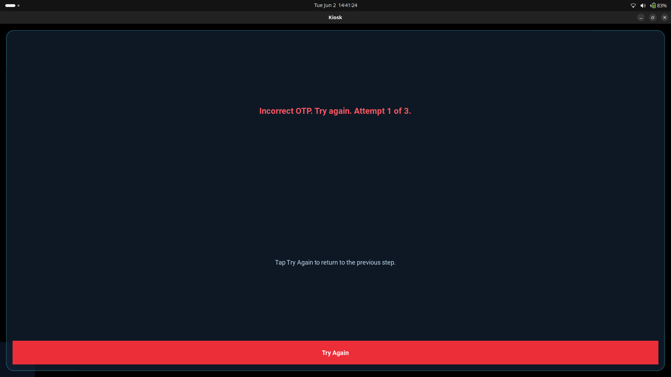
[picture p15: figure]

Figure 5.12: Incorrect OTP screen

- Temporary PIN screen, for first time users, the system prompts a student to enter a temporary PIN before setting their new PIN. The system uses two-factor authentication to enhance security during collection of delicate and crucial information of the student.

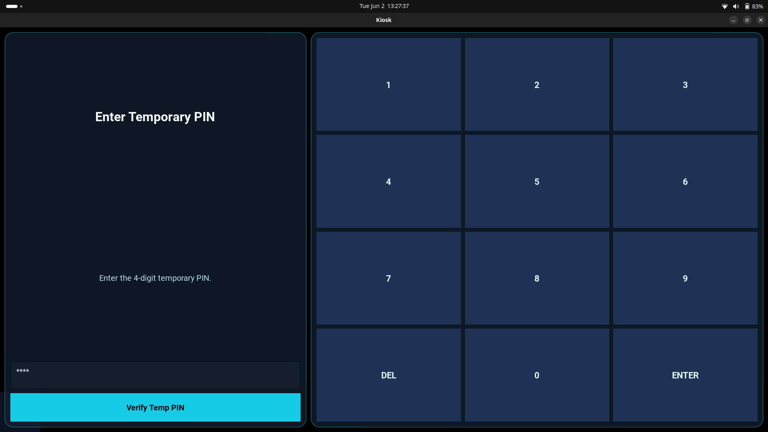
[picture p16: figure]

Figure 5.13:Temporary PIN screen – intial

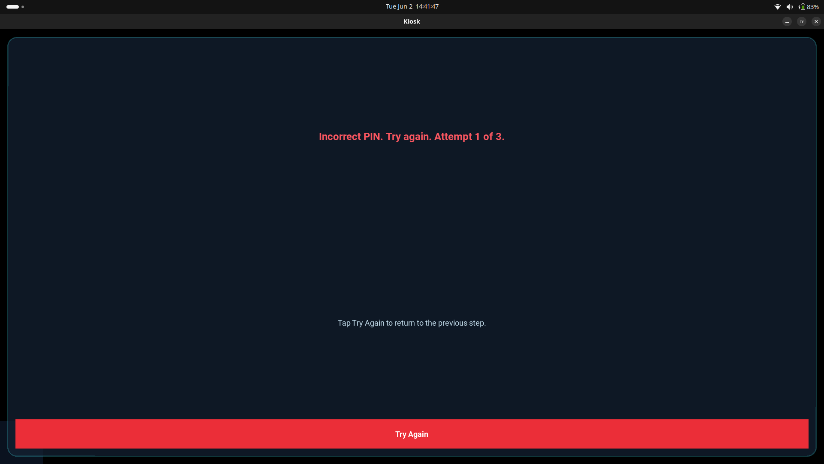
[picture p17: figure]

Figure 5.14: Incorrect PIN entered

- Card dispensing screen, this is a placeholder for hardware background activites. After setting the new pin, raspberry pi gives command to STM32 controller via SPI protocol to start card ejection process.

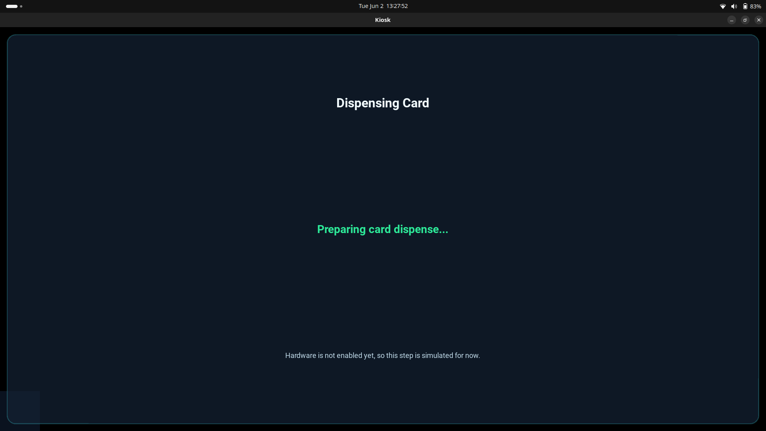
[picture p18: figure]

Figure 5.15: Hardware card dispensing - background

- Confirmation screen, this is the final screen that shows the student has already collected the card. This screen ends the session, and also audit all the logs into the database.

Figure 5.16: Final confirmation screen

### 5.1.3 OTP GENERATION AND VERIFICATION

On the implementation of OTP generation, python secrets module was used for cryptographic randomness, producing six digit numeric codes as shown in figure 5.17. In addition to that, figure 5.18 shows that the storage of these OTP codes were done by bcrypt hashing with salt rounds set to 12, preventing rainbow table attacks. The codes have 24 hour validity window from the generation timestamp, which can be changed on the main configuration file as the system admin wishes.

Figure 5.17: OTP generation

Figure 5.18: Bcrypt hashing with salt rounds

Delivery of the OTP is distributed into email, and SMS. For SMS, BRIQ Solutions’ API was used to send out messages to the required student (as the information is present in the database) while email app was used to send messages to default students’ emails provided by the University.

### 5.1.4 UNIVERSITY API INTEGRATION AND SLOT ASSIGNMENT

The OCR extracted registration numbers are validated against the University database. The University database used was the mock database with almost the same like architecture for the real one with simplicity and not strict security just for the prototype. The endpoint called by the raspberry Pi is HTTPS GET /students/{reg_number}. Authentication used is the bearer key which is also found in the configuration files. Timeout for the API call is 5 seconds with exponential back off retries with a maximum of 3 attempts.

The said API call handles file names such as first_name, surname, phone_number, email and other like personal information.

Upon successful validation, the system assigns an active slot on the round storage platform. The Round-robin allocation among three active slots (0-2) which are scalable. The application looks for a free slot in the database (slot_index) and puts the scanned card into the slot. The card scanned is linked to scan timestamp data and batch ID which are also stored in the database.

## 5.2 DATABASE ARCHITECTURE – KIOSK LOCAL

The SQLite database has data with five normalized tables designed for audit compliance and query efficiency.

Table 5.1: Schema overview

TABLES | COLUMNS | PURPOSE
Students | id (PK), registration_number (UNIQUE), first_name, last_name, email, phone, programme, status | Student master records; single source of truth for student information
Authentication | d (PK), student_id (FK), otp_hash, otp_generated_at, otp_verified_at, temp_pin_hash, permanent_pin_hash, is_temp_pin, failed_otp_count, failed_pin_count, otp_lockout_until, pin_lockout_until, last_activity | Credential storage with bcrypt hashes; lockout state management
Cards | id (PK), card_number (UNIQUE), student_id (FK), slot_index, batch_id (FK), status (pending_collection or collected or rejected), created_at, collected_at | Physical card tracking; links students to assigned dispenser slots
Audit Log | id (PK), registration_number, session_id, event_type (registration or otp_generated or otp_verified or pin_verified or card_collected or error), failure_reason, timestamp | Immutable append-only log for regulatory audit trail
Batches | id (PK), batch_name, staff_id, card_count, scanned_at | Metadata for batch ingestion events

For this presented schema overview, the indexing strategy in those columns goes as follows; in students table, registration numbers for fast student lookup during collection, in audit log, chronological log traversal and for cards, student_id and status for query pending cards for given students.

## 5.3 API CLIENT MODULE AND SMS DELIVERY

From the application, a module dedicated for api client activites abstracts communication with the mock university database. The key features are as follows:

- mDNS discovery: automatically resolves university-db.local (my computer for this prototype) on startup with a requirement of Avahi daemon package
- Bearer key, a security configurable API key in the configuration file
- Timeout handling, 5 second timeout with exponential backoff with maximum of 3 attempts.
- Fallback caching, this returns the cached student records if the network is unavailable.

After the OTP generation, the system was configured to use BRIQ Solutions, a Tanzania – based SMS gateway with the following configuration requirements:

- BRIQ API KEY: authentication token from one’s own BRIQ account.
- BRIQ SENDER ID: sender name to be displayed to the reciever. For this project, the sender ID is CARD KIOSK
- BRIQ BASE URL: endpoint that communicates the application and the BRIQ’s dedicated account.

From all these configuration, sending message from the application to student’s personal number retrieved from the Universtiy database is made possible. The following are the steps towards sending the SMS:

i. Construction of a message with OTP generated with a temporary PIN for first users.
ii. POST request to BRIQ “/v1/message/send-instant” with a referenced API key.
iii. Log the delivery status to the audit log table
iv. On failure, queue for retry every 15 minutes (up to 3 attempts)

Credential delivery is only considered successful when at least one channel (SMS or email) proceeds. This means that the receiver has got the OTP successfully.

## 5.4 SESSION MANAGEMENT

The session manager class maintains per transaction states in volatile memory (RAM). Initialization of a session is done on the registration number entry on the UI, with state varibales such as validated flags on OTP and PIN, assigned slot index, and student ID. Teardown is done on the end of transaction or inactivity for a timeout of 60 seconds. The session ID is logged into the audit log for transaction correlation.

## 5.5 CONFIGURATION MANAGEMENT

In the raspberry Pi application, a dedicated module that centralized all configurable parameters is implemented but isolated from the version control due to presence of critical secrets such as API KEYS, and passwords. The parameters contained in there are:

- Database: DB_PATH, connection for the database
- APIs: UNIVERSITY_API_BASE_URL, UNIVERSITY_API_KEY, timeouts, retry policies
- SMS: BRIQ_API_KEY, BRIQ_SENDER_ID, BRIQ_BASE_URL
- Email: SMTP_EMAIL, SMTP_PASSWORD (app-specific, not account password)
- Camera: Device candidates, capture resolution (1920×1440), frame rate, thresholds
- OCR: Perspective correction size, registration ROI coordinates, preprocessing values
- UI: Timeout intervals, attempt limits, lockout durations

# CHAPTER SIX: HARDWARE IMPLEMENTATION

## 6.1 MICROCONTROLLER SELECTION AND CONFIGURATION

The current project hardware implementation targets Arduino Mega 2560, a 16MHz AVR based micro controller as shown in the figure 6.1, with the following hardware specifications:

- Clock speed: 16 MHz crystal oscillator
- Memory: 256 KB Flash, 8 KB SRAM, 4 KB EEPROM
- GPIO Pins: 54 digital I/O, 16 analog inputs
- Hardware Peripherals: SPI (slave mode), UART (serial monitor), PWM timers
- Programming: PlatformIO framework with AVR HAL abstractions in Visual Studio Code IDE

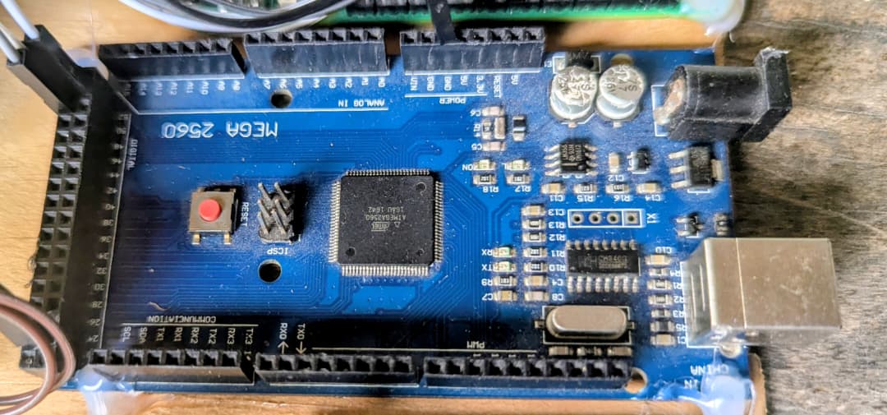
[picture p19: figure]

Figure 6.1: Arduino Mega micro-controller

The original microcontroller choice was STM32 Nucleo-F401RE with 1MHz SPI, but this substitution due to logistics maintains compatibility through platformIO abstraction with an improvise of speed for SPI at 100 kHz.

## 6.2 SPI SLAVE CONFIGURATION

The micro-controller operates as a slave (SPI), receiving two-byte ASCII frame commands from the raspberry Pi master. The pin mapping of the connection configuration is as follows:

- SS (Slave Select): pin 53 (active low), with pin 24 from Raspberry Pi
- MOSI (Master Out Slave In): pin 51, with pin 19 from Raspberry Pi
- SCK (Serial Clock): pin 52, with pin 23 from Raspberry Pi

With considerations of different operating voltages between Raspberry Pi and the arduino Mega, since the slave does not send any signal to its master, hence no level shifting is required.

## 6.3 SPI COMMUNICATION PROTOCOL

The current implementation uses a two-byte ASCII frame format:

- Byte 0: command character (0 – 9, A – Z)
- Byte 1: parameter character (0 – 9, slot index)

Example status frames are:

- “00”: processing error
- “1X”: 1 – success, X – slot index
- “2X”: 2 – retrieve, X – slot index

The current firmware implements basic frame reception and servo test routines.

## 6.4 SERVO MOTOR CONTROL

The firmware configures hardware PWM outputs for servo motor controls. The servo type in conversation is SG90 with 180 degrees physical constraints.

- Pin 22: card holder for scanning card during entrance
- Pin 23: carousel rotation motor controlled

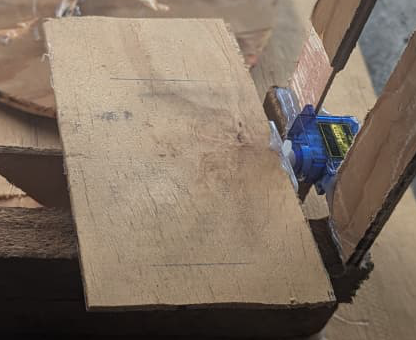
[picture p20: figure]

Figure 6.2: Servo motor attached to card holder

For servo control, pulses vary from 544 µs to 2400 µs, to rotate from 0 to 180 degrees.

## 6.5 FIRMWARE ARCHITECTURE

The arduino Mega firmware follows a cooperative multitasking pattern with SPI hardware interrupts. The main loop structures goes as follows:

- Poll SPI SPIE flag for received framework

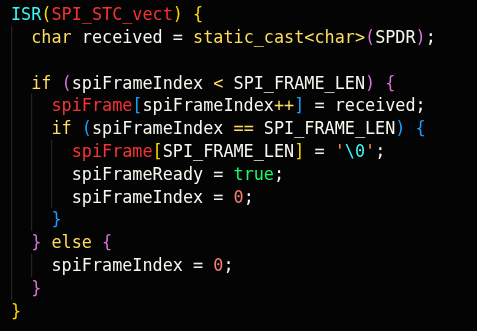
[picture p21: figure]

Figure 6.3: SPI poll initialization

- Extract two-byte command and parameter from SPI buffer

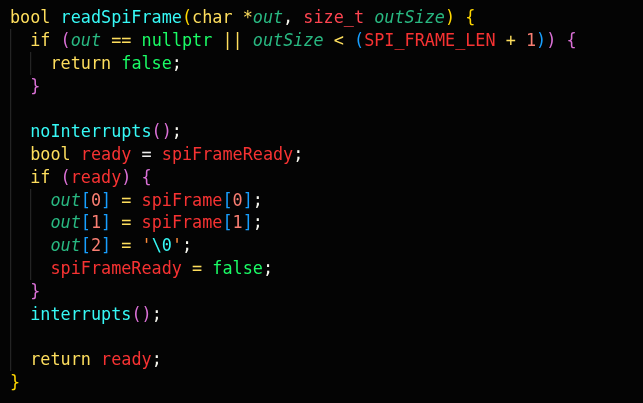
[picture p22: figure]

Figure 6.4: Frame extraction from buffer

- Dispatch command to state machine

Figure 6.5: Dispatch to state machine

- Drive servo motors according to the received SPI buffer.

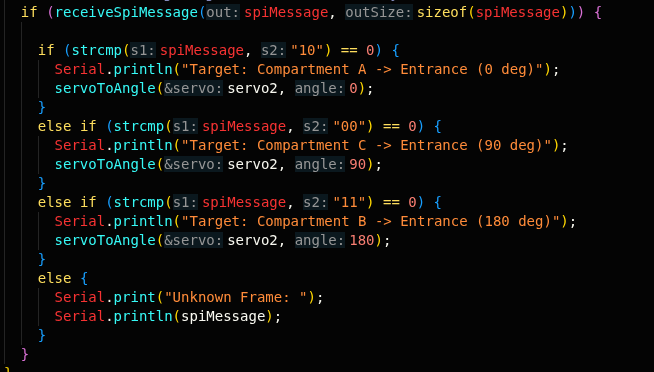
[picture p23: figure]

Figure 6.5: Choice statements
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

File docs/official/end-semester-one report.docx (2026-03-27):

UNIVERSITY OF DAR ES SALAAM

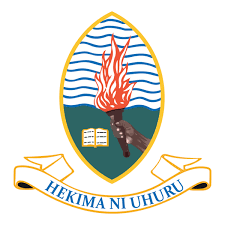
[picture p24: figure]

COLLEGE OF INFORMATION AND COMMUNICATION TECHNOLOGY

DEPARTMENT OF ELECTRONICS AND TELECOMMUNICATIONS ENGINEERING

FINAL YEAR REPORT-MID SEMESTER ONE

PROJECT TITLE: DESIGN AND IMPLEMENTATION OF AN AUTOMATIC ID CARD ISSUANCE SYSTEM

Student’s Name: Samuel Dan Musyani

Registration Number: 2022-04-09050

Supervisor’s Name: Dr. Hashimu Iddi

Supervisor’s Signature:
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

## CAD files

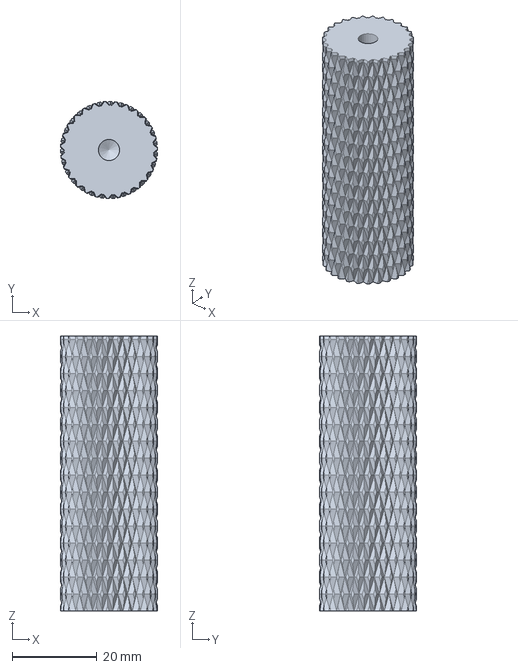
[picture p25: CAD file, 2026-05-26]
hardware/FreeCAD/Design/stepper_motor_roller.FCStd
23.0 x 23.0 x 65.0 mm

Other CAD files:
hardware/FreeCAD/Exports/stepper_motor_roller-Body.stl

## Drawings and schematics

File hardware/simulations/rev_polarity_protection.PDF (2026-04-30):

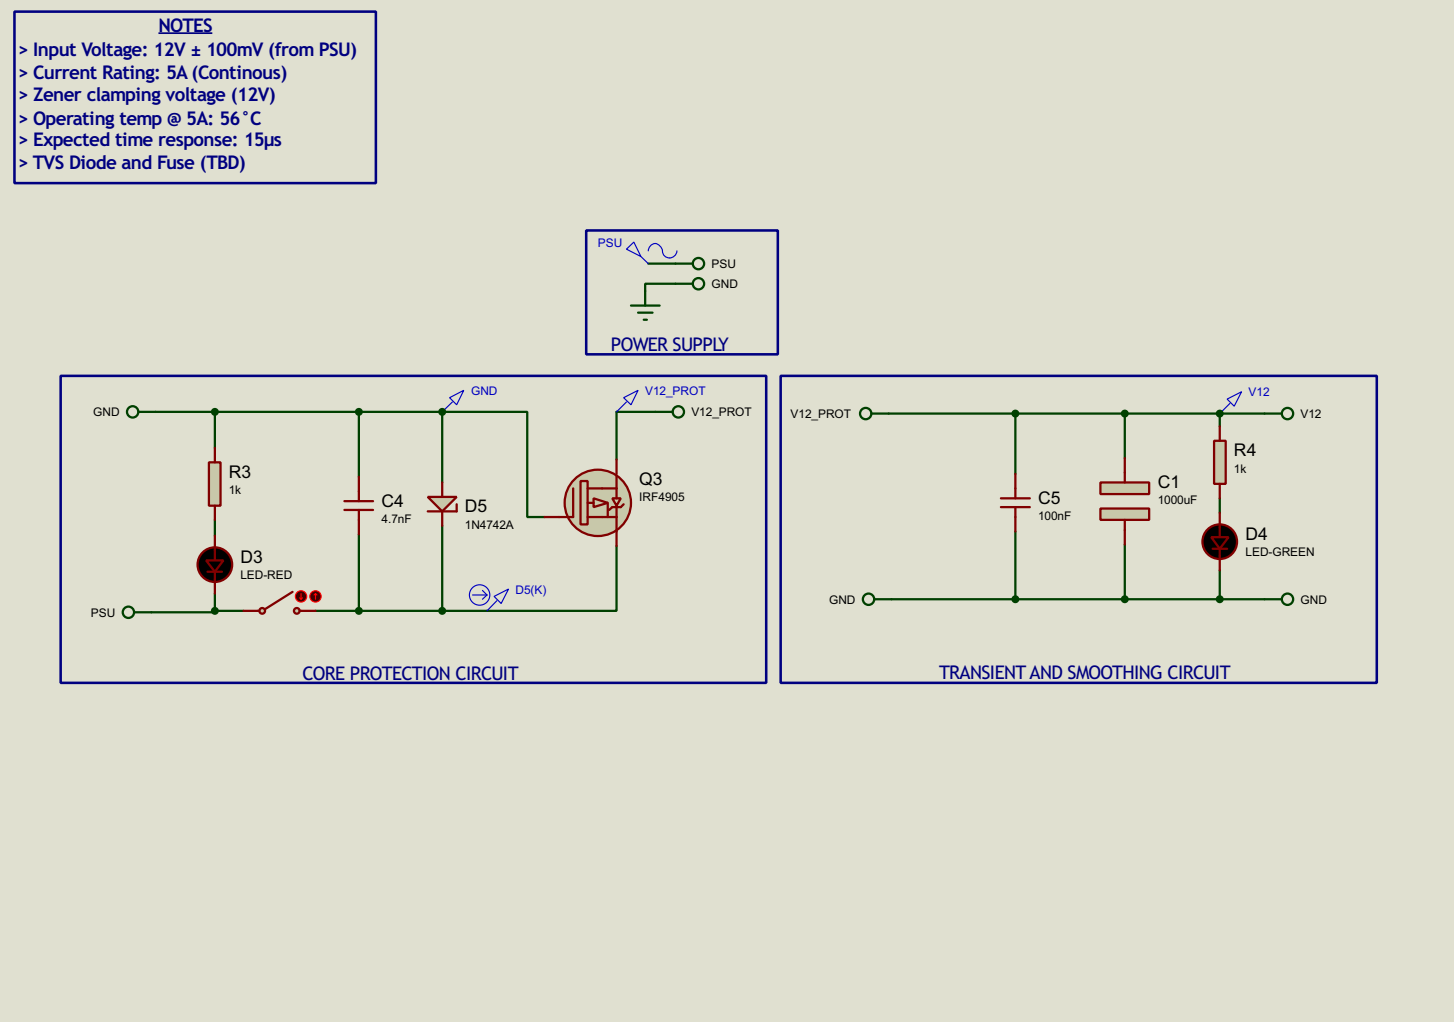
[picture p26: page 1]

NOTES > Input Voltage: 12V ± 100mV (from PSU) > Current Rating: 5A (Continous) > Zener clamping voltage (12V)

> Operating temp @ 5A: 56°C
> Expected time response: 15µs
> TVS Diode and Fuse (TBD)

TRANSIENT AND SMOOTHING CIRCUIT

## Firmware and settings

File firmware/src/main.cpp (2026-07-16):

#include <Arduino.h>
#include <Servo.h>
#include <SPI.h>
#include <Stepper.h>
#include <string.h>

// 28BYJ-48 Stepper & Driver Pin Mapping
#define STEP_IN1 30
#define STEP_IN2 31
#define STEP_IN3 32
#define STEP_IN4 33

// Objects
Servo servo1; // Card holder (Pin 22)

// Pin definitions
#define SERVO1 22

// Stepper Motor Configuration
constexpr int STEPS_PER_REV = 2048; 
constexpr int STEP_SPEED_RPM = 5;   // Reduced to 5 RPM to maximize torque and prevent card slippage

// Absolute Stepper Targets (Entrance Positions)
constexpr int STEP_POS_A = 0;    // Compartment A: 0°
constexpr int STEP_POS_B = 683;  // Compartment B: 120°
constexpr int STEP_POS_C = 1365; // Compartment C: 240° (Also acts as Failure/Reject slot)

// Absolute Stepper Targets (Exit Positions = Entrance + 1024 steps)
constexpr int STEP_EXIT_A = 1024; // Compartment A at Exit (180°)
constexpr int STEP_EXIT_B = 1707; // Compartment B at Exit (120° + 180° = 300°)

// State Tracking
int currentStep = 0; // Tracks absolute stepper position relative to home (A)

// Note: Pin order must be (IN1, IN3, IN2, IN4) for 28BYJ-48 sequence
Stepper stepper(STEPS_PER_REV, STEP_IN1, STEP_IN3, STEP_IN2, STEP_IN4);

// Hardware SPI pins on the Mega 2560
constexpr uint8_t SPI_SS_PIN = 53;
constexpr uint8_t SPI_MOSI_PIN = 51;
constexpr uint8_t SPI_MISO_PIN = 50;
constexpr uint8_t SPI_SCK_PIN = 52;

// SPI status frames from Raspberry Pi: "1X" for Entrance, "2X" for Exit, "00" for OCR Error
constexpr uint8_t SPI_FRAME_LEN = 2;

volatile char spiFrame[SPI_FRAME_LEN + 1] = {0};
volatile uint8_t spiFrameIndex = 0;
volatile bool spiFrameReady = false;

// Servo Pulse Constants
constexpr int ORIGIN_PULSE = 544;  
constexpr int MAX_PULSE = 2400;    

// Functions
void setupSpiReceiver();
bool receiveSpiMessage(char *out, size_t outSize);
void servoToOrigin(Servo &servo);
void servoToAngle(Servo &servo, int angle);
void moveStepperToStep(int targetStep);

ISR(SPI_STC_vect) {
  char received = static_cast<char>(SPDR);

  if (spiFrameIndex < SPI_FRAME_LEN) {
    spiFrame[spiFrameIndex++] = received;
    if (spiFrameIndex == SPI_FRAME_LEN) {
      spiFrame[SPI_FRAME_LEN] = '\0';
      spiFrameReady = true;
      spiFrameIndex = 0;
    }
  } else {
    spiFrameIndex = 0;
  }
}

void setup() {
  Serial.begin(115200);
  Serial.println("System initializing!");
  delayMicroseconds(10);

  setupSpiReceiver();

  // Initialize Stepper Motor Speed
  stepper.setSpeed(STEP_SPEED_RPM);

  // Pre-load the 0-degree pulse width BEFORE attaching to prevent startup jumps
  servo1.writeMicroseconds(ORIGIN_PULSE);
  delayMicroseconds(10);

  // Attach card holder servo
  servo1.attach(SERVO1);
  delayMicroseconds(100);

  // Verify homing alignment softly
  Serial.println("Homing verification...");
  servoToOrigin(servo1);

  // Boot assumption: Carousel is physically aligned to Compartment A (0 deg)
  currentStep = STEP_POS_A;

  Serial.println("System Ready! Awaiting SPI commands...");
}

void loop() {
  // Clear software buffer whenever the Pi releases Chip Select (SS Pin goes HIGH)
  if (digitalRead(SPI_SS_PIN) == HIGH) {
    spiFrameIndex = 0;
  }
  
  char spiMessage[SPI_FRAME_LEN + 1];

  if (receiveSpiMessage(spiMessage, sizeof(spiMessage))) {
    
    // --- ENTRANCE & FAILURE ROUTINES ("1X" / "00") ---
    
    if (strcmp(spiMessage, "10") == 0) {
      Serial.println("Target: Compartment A -> Entrance (0 deg)");
      moveStepperToStep(STEP_POS_A);
      delay(2000); 
      
      servoToAngle(servo1, 70);
      delay(1000); 
      servoToOrigin(servo1);
    } 
    else if (strcmp(spiMessage, "11") == 0) {
      Serial.println("Target: Compartment B -> Entrance (120 deg)");
      moveStepperToStep(STEP_POS_B);
      delay(2000); 
      
      servoToAngle(servo1, 70);
      delay(1000); 
      servoToOrigin(servo1);
      
      // Return carousel to OG position (Compartment A)
      moveStepperToStep(STEP_POS_A); 
      delay(2000); 
    }
    else if (strcmp(spiMessage, "12") == 0 || strcmp(spiMessage, "00") == 0) {
      if (strcmp(spiMessage, "00") == 0) {
        Serial.println("Target: OCR Error/Failure -> Routing to Compartment C (240 deg)");
      } else {
        Serial.println("Target: Compartment C -> Entrance (240 deg)");
      }
      moveStepperToStep(STEP_POS_C);
      delay(2000); 
      
      servoToAngle(servo1, 70);
      delay(1000); 
      servoToOrigin(servo1);
      
      // Return carousel to OG position (Compartment A)
      moveStepperToStep(STEP_POS_A); 
      delay(2000); 
    } 

    // --- EXIT ROUTINES ("2X") ---
    
    else if (strcmp(spiMessage, "20") == 0) {
      Serial.println("Target: Compartment A -> Exit (180 deg)");
      moveStepperToStep(STEP_EXIT_A);
      delay(2000); // Settle time at physical exit (Servo 1 does nothing)
      
      // Return carousel to OG position (Compartment A)
      moveStepperToStep(STEP_POS_A);
      delay(2000);
    }
    else if (strcmp(spiMessage, "21") == 0) {
      Serial.println("Target: Compartment B -> Exit (300 deg)");
      moveStepperToStep(STEP_EXIT_B);
      delay(2000); // Settle time at physical exit (Servo 1 does nothing)
      
      // Return carousel to OG position (Compartment A)
      moveStepperToStep(STEP_POS_A);
      delay(2000);
    }
    else {
      Serial.print("Unknown SPI Frame: ");
      Serial.println(spiMessage);
    }
  }
}

// SPI INFRASTRUCTURE FUNCTIONS

void setupSpiReceiver() {
  pinMode(SPI_SS_PIN, INPUT_PULLUP);
  pinMode(SPI_MOSI_PIN, INPUT);
  pinMode(SPI_SCK_PIN, INPUT);
  pinMode(SPI_MISO_PIN, OUTPUT);

  SPCR |= _BV(SPE);
  SPI.attachInterrupt();
}

bool readSpiFrame(char *out, size_t outSize) {
  if (out == nullptr || outSize < (SPI_FRAME_LEN + 1)) {
    return false;
  }

  noInterrupts();
  bool ready = spiFrameReady;
  if (ready) {
    out[0] = spiFrame[0];
    out[1] = spiFrame[1];
    out[2] = '\0';
    spiFrameReady = false;
  }
  interrupts();

  return ready;
}

bool receiveSpiMessage(char *out, size_t outSize) {
  if (!readSpiFrame(out, outSize)) {
    return false;
  }

  Serial.print("Received SPI: ");
  Serial.println(out);
  return true;
}

// ROBUST STEPPER MOTION CONTROL FUNCTION

void moveStepperToStep(int targetStep) {
  int stepsToMove = targetStep - currentStep;
  
  if (stepsToMove != 0) {
    Serial.print("Moving stepper from ");
    Serial.print(currentStep);
    Serial.print(" to ");
    Serial.print(targetStep);
    Serial.print(" (Steps: ");
    Serial.print(stepsToMove);
    Serial.println(")");
    
    stepper.step(stepsToMove);
    currentStep = targetStep;
  }
}

// ROBUST SERVO MOTION CONTROL FUNCTIONS

void servoToOrigin(Servo &servo) {
  int currentPulse = servo.readMicroseconds();
  
  if (currentPulse == ORIGIN_PULSE) {
    return; 
  }

  if (currentPulse < ORIGIN_PULSE) {
    for (int p = currentPulse; p <= ORIGIN_PULSE; p++) {
      servo.writeMicroseconds(p);
      delayMicroseconds(1500); 
    }
  } else {
    for (int p = currentPulse; p >= ORIGIN_PULSE; p--) {
      servo.writeMicroseconds(p);
      delayMicroseconds(1500); 
    }
  }
}

void servoToAngle(Servo &servo, int angle) {
  int targetPulse = map(angle, 0, 180, ORIGIN_PULSE, MAX_PULSE);
  targetPulse = constrain(targetPulse, ORIGIN_PULSE, MAX_PULSE);

  int currentPulse = servo.readMicroseconds();

  if (currentPulse < targetPulse) {
    for (int p = currentPulse; p <= targetPulse; p++) {
      servo.writeMicroseconds(p);
      delayMicroseconds(500); 
    }
  } else {
    for (int p = currentPulse; p >= targetPulse; p--) {
      servo.writeMicroseconds(p);
      delayMicroseconds(2000);
    }
  }
  delay(1000);
}

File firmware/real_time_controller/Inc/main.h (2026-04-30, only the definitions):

#define B1_Pin GPIO_PIN_13
#define B1_GPIO_Port GPIOC
#define USART_TX_Pin GPIO_PIN_2
#define USART_TX_GPIO_Port GPIOA
#define USART_RX_Pin GPIO_PIN_3
#define USART_RX_GPIO_Port GPIOA
#define SOLENOID_Pin GPIO_PIN_10
#define SOLENOID_GPIO_Port GPIOA
#define HALL_EFFECT_Pin GPIO_PIN_11
#define HALL_EFFECT_GPIO_Port GPIOA
#define TMS_Pin GPIO_PIN_13
#define TMS_GPIO_Port GPIOA
#define TCK_Pin GPIO_PIN_14
#define TCK_GPIO_Port GPIOA
#define SWO_Pin GPIO_PIN_3
#define SWO_GPIO_Port GPIOB
#define IR1_Pin GPIO_PIN_4
#define IR1_GPIO_Port GPIOB
#define IR2_Pin GPIO_PIN_5
#define IR2_GPIO_Port GPIOB
#define IR3_Pin GPIO_PIN_6
#define IR3_GPIO_Port GPIOB
#define IR4_Pin GPIO_PIN_7
#define IR4_GPIO_Port GPIOB

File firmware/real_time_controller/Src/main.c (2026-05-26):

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
/* Includes ------------------------------------------------------------------*/
#include "main.h"

/* USER CODE BEGIN PTD */

#define SPI_FRAME_SIZE 3

// Command Codes
#define CMD_ROTATE_TO_SLOT    0x10
#define CMD_EJECT_CARD        0x11
#define CMD_LATCH_CARD        0x12
#define CMD_RELEASE_LATCH     0x13
#define CMD_LOCK_DOOR         0x20
#define CMD_UNLOCK_DOOR       0x21
#define CMD_FEED_CARD         0x30
#define CMD_DIVERT_REJECT     0x31
#define CMD_GET_SENSOR_STATE  0x40
#define CMD_HOME_CAROUSEL     0x41

// Response Codes
#define RESP_ACK              0x00
#define RESP_NACK             0x01
#define RESP_BUSY             0x02
#define RESP_SENSOR_STATE     0x03
#define RESP_ERROR            0x04

/* USER CODE END PTD */

SPI_HandleTypeDef hspi1;

TIM_HandleTypeDef htim1;
TIM_HandleTypeDef htim2;

UART_HandleTypeDef huart2;

/* USER CODE BEGIN PV */

uint8_t spi_rx_buf[3] = {0};
uint8_t spi_tx_buf[3] = {RESP_ACK, 0x00, 0x00};  // Pre-load with default ACK
uint8_t rx_byte_count = 0;
uint8_t spi_frame_ready = 0;

/* USER CODE END PV */

void SystemClock_Config(void);
static void MX_GPIO_Init(void);
static void MX_USART2_UART_Init(void);
static void MX_SPI1_Init(void);
static void MX_TIM1_Init(void);
static void MX_TIM2_Init(void);
/**
  * @brief  The application entry point.
  * @retval int
  */
int main(void)
{

  /* MCU Configuration--------------------------------------------------------*/

  /* Reset of all peripherals, Initializes the Flash interface and the Systick. */
  HAL_Init();

  /* Configure the system clock */
  SystemClock_Config();

  /* Initialize all configured peripherals */
  MX_GPIO_Init();
  MX_USART2_UART_Init();
  MX_SPI1_Init();
  MX_TIM1_Init();
  MX_TIM2_Init();
  /* USER CODE BEGIN 2 */

  // Start SPI1 in interrupt mode - listen from Pi
  HAL_SPI_TransmitReceive_IT(&hspi1, spi_tx_buf, spi_rx_buf, SPI_FRAME_SIZE);

  /* USER CODE END 2 */

  /* Infinite loop */
  /* USER CODE BEGIN WHILE */
  while (1)
  {
    /* USER CODE END WHILE */

    /* USER CODE BEGIN 3 */
  }
  /* USER CODE END 3 */
}

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
/* USER CODE BEGIN 4 */

void route_command(uint8_t cmd_byte, uint8_t param_byte)
{
  switch (cmd_byte) {
    case 0x42:
    	spi_tx_buf[0] = cmd_byte;
    	spi_tx_buf[1] = param_byte;
    	spi_tx_buf[2] = cmd_byte ^ param_byte;
    	break;
    
    default: 
    	spi_tx_buf[0] = RESP_NACK;
    	spi_tx_buf[1] = cmd_byte;
    	spi_tx_buf[2] = spi_tx_buf[0] ^ spi_tx_buf[1];
    	break;
  }
}

/* USER CODE END 4 */
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


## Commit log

2026-03-28 feat: retry logic, and handled send failures
    [auth.py]
2026-03-28 feat: pin hashing and verification implementation
2026-03-28 feat: completed temporary PIN flow
2026-03-28 fix: added security checks before the main operation - lockout
    [auth.py]
2026-03-29 feat: finished implementation and sms phase - SMS delivery still a problem
    [auth.py, sms_client.py, test_auth.py]
2026-04-01 fix: africastalking to briq - imports, config.example
    [database.py, ocr.py, session_manager.py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]
2026-04-01 docs: updated fixing tasked guideline
    [sms_client.py]
2026-04-02 fix: added briq's new api - formating number, requests
    [auth.py, sms_client.py, test_auth.py]
2026-04-02 feat: added scrrens - idle, locked, success and pin setup
2026-04-03 feat: spi implementation - frames, tables and docs
2026-04-03 feat: implemented SPI master driver functions
2026-04-07 feat: added UI style, and wired pin, reg and otp to backend
2026-04-07 docs: guideline to circuit design
2026-04-10 docs: added values for circuit design
2026-04-11 docs: refined and added design parameters - 12-5V buck
2026-04-17 docs: added build descriptions - reverse polarity
    [test_auth.py]
2026-04-20 feat: added capacitor - reverse polarity:
2026-04-23 fix: changed N-mosfet to P-mosfet - reverse polarity protection
2026-04-23 fix: calculated P-mosfet design values
2026-04-24 feat: added core working circuit - reverse polarity protection
2026-04-27 feat: refined schematic export - reverse
2026-04-27 feat: added altium files - schematic circuit creation
    [rev_polarity_protection.PrjPcb, rev_polarity_protection.SchDoc]
2026-04-27 feat: added kicad schematic file
    [rev_polarity_prot.kicad_pcb, rev_polarity_prot.kicad_sch]
2026-04-28 feat: configured GPIO pins - stm32
2026-04-29 feat: added circuit components - 0.62R not found
    [rev_polarity_protection.SchDoc]
2026-04-29 fix: api calling by pi - tested in pc only
    [api_client.py]
2026-05-04 fix: added a new reverse polarity circuit
    [rev_polarity_protection.SchDoc, reverse-polarity-protection.PcbDoc, reverse-polarity-protection.PrjPcb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]
2026-05-04 feat: added schematic library
    [my-library.SchLib, reverse-polarity-protection.PrjPcb, reverse-polarity-protection.SchDoc]
2026-05-04 feat: initated schematic symbol creation - reverse polarity protection
    [my-library.SchLib, reverse-polarity-protection.PrjPcb, reverse-polarity-protection.SchDoc]
2026-05-05 fix: deleted my library
    [my-library.SchLib, reverse-polarity-protection.PrjPcb, reverse-polarity-protection.SchDoc]
2026-05-06 docs: finalizing design parameters - buck converter"
    .
2026-05-09 feat: redesigned circuit - own library
    [reverse-polarity-protection.SchDoc]
2026-05-09 feat: added buck converter circuit
    [buck_converter.PcbDoc, buck_converter.PrjPcb, buck_converter.SchDoc]
2026-05-09 feat: added new simulation circuit, datasheet
2026-05-10 docs: added schottky diode
2026-05-10 feat: implemented a new buck converter circuit
    [buck_converter.kicad_sch]
2026-05-10 fix: gate resistor added & clamp diode corrected
    [rev_polarity_prot.kicad_sch]
2026-05-12 feat: assigned footprints
    [buck_converter.kicad_sch]
2026-05-12 feat: function of interrupt and callback - firmware
2026-05-14 feat: firmware running - SPI listening
2026-05-14 fix: tested out SPI communication - works
    [test_spi.py]
2026-05-15 feat: added 3D design file - roller
    [stepper_motor_roller.FCStd]
2026-05-15 feat: added a body roller 3D file
    [stepper_motor_roller.FCStd]
2026-05-15 feat: refined paramters for roller
    [stepper_motor_roller.FCStd]
2026-05-16 feat: added inductor & buck schematic capture
    [buck_converter.PrjPcb, buck_converter.SchDoc]
2026-05-20 fix: refined roller parameters
    [stepper_motor_roller.FCStd]
2026-05-25 feat: added buck converter placements'
    [buck_converter.PcbDoc]
2026-05-25 feat: redesigned stepper motor roller
    [stepper_motor_roller.FCStd]
2026-05-25 fix: refined stepper motor roller - ready for printing
    [stepper_motor_roller-Body.stl, stepper_motor_roller.FCStd]
2026-05-26 feat: implemented a new rev polarity circuit
    [buck_converter.PcbDoc, buck_converter.PrjPcb, buck_converter.SchDoc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]
2026-05-26 refined circuit
    [reverse_pol_protection.PrjPcb, reverse_pol_protection.SchDoc]
2026-05-26 feat: added terminal block
    [buck_converter.PrjPcb, reverse_pol_protection.SchDoc]
2026-05-26 feat: completed schematics - both circuits
    [buck_converter.SchDoc]
2026-05-26 feat: completed schematics for circuits
    [buck_converter.PrjPcb, buck_converter.SchDoc]
2026-05-26 feat: added inductor footprint
    [buck_converter.SchDoc]
2026-05-27 fix: linked footprints with schematic - rev_pol circuit
    [buck_converter.PrjPcb, reverse_pol_protection.PrjPcb, reverse_pol_protection.SchDoc]
2026-05-28 feat: added pcb file - reverse_pol
    [reverse_pol_protection.PcbDoc, reverse_pol_protection.SchDoc]
2026-05-28 feat: implemented pcb outline and component placement
    [reverse_pol_protection.PcbDoc, reverse_pol_protection.PrjPcb, reverse_pol_protection.SchDoc]
2026-05-28 feat: added pcb routing
    [reverse_pol_protection.PcbDoc, reverse_pol_protection.SchDoc]
2026-05-28 feat: implemented pcb routing
    [reverse_pol_protection.PcbDoc, reverse_pol_protection.PrjPcb, reverse_pol_protection.SchDoc]
2026-05-29 fix: clearance problem
    [reverse_pol_protection.PcbDoc, reverse_pol_protection.PrjPcb, reverse_pol_protection.SchDoc]
2026-05-29 feat: implemented pcb design - rev_pol
    [reverse_pol_protection.PcbDoc]
2026-05-29 feat: completed PCB design for buck converter
    [buck_converter.PcbDoc, buck_converter.PrjPcb, buck_converter.SchDoc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]
2026-05-31 feat: added card outline detector script
    [buck_converter.kicad_pcb, buck_converter.kicad_sch]
2026-05-31 feat: implemented perspective correction
    [card_detector.py]
2026-05-31 fix: implemented roi thresholds
    [card_detector.py, ocr.py]
2026-06-01 fix: adjusted for a suitable thresholding
    [card_detector.py, ocr.py]
2026-06-01 fix: workflow issue, created kiosk_db - not documented shit
    [card_detector.py, database.py, ocr.py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]
2026-06-01 fix: rewire UI and refined graphics
    [auth.py, database.py, session_manager.py]
2026-06-01 feat: PA1 pin to DIR - for carousel
2026-06-02 fix: removed scanning camera
2026-06-02 feat: refined report
    [buck_converter.PcbDoc, reverse_pol_protection.PcbDoc]
2026-06-02 feat: added arduino MEGA testing files
2026-06-02 fix: revert back to STM32
    [main.cpp]
2026-06-02 feat: motor rotates, not smooothly - stepper
2026-06-04 fix: restarted project - configured card-servo
    [main.c, main.h]
2026-06-04 feat added servo function file
2026-06-15 feat: added a test firmware - arduino mega
2026-06-15 feat: added servo checking function
2026-06-15 fix: sms and email sending - api lookup
    [api_client.py]
2026-06-16 feat: simulation for motors
2026-06-16 fix: removed mega firmware
    [main.cpp]
2026-06-16 feat: added stepper motor schematic
    [stepper-motor.kicad_sch]
2026-06-16 feat: added servo connection schematic
    [servo-motor.kicad_pcb, servo-motor.kicad_sch]
2026-06-17 fix: thermal relief on copper pour
    [reverse_pol_protection.PcbDoc]
2026-06-17 feat: added hall sensor
2026-06-17 feat: added phone camera file
2026-06-17 feat: added phone-camera function
2026-06-19 fix: changed to mega
    [main.c, main.cpp, main.h]
2026-06-19 feat: tested servo - runs correctly
    [main.cpp]
2026-06-19 fix: found center - servo motor
    [main.cpp]
2026-06-19 docs: datasheet - hall sensor & servo
2026-06-20 fix: changed pins
    [stepper-motor.kicad_sch]
2026-06-23 fix: stepper motor testing - not ready
    [main.cpp]
2026-06-24 feat: testing camera phone connection
2026-06-24 fix: stepper motor test - success
    [stepper-motor.kicad_sch]
2026-06-28 fix: stable motor rotation - stepper
    [main.cpp]
2026-06-29 feat: initiated SPI - mega and Pi
2026-06-29 feat: added SPI recieving - mega
2026-06-29 feat: added hall sensor - testing
2026-07-02 fix: camera as phone - USB webcam
    [database.py]
2026-07-08 feat: added card holder control - camera
2026-07-12 fix: edited spi comms
    [main.cpp, ocr.py, spi_master.py]
2026-07-12 fix: spi - global lifecycle connection
    [main.cpp, ocr.py, spi_master.py]
2026-07-12 fix: pi communicated with mega - spi
    [ocr.py, spi_master.py]
2026-07-12 fix: spi comm - mega side
    [main.cpp]
2026-07-12 feat: implemented control and communication - spi + mega
2026-07-13 fix: updated report - final report V2
    [main.cpp]
2026-07-14 feat: added spi to UI
2026-07-14 feat: connected ui with mega - spi
2026-07-16 feat: added keypad to pin screen
2026-07-16 fix: stepper motor for UI
    [main.cpp]
2026-07-16 fix: editable running scripts
    [spi_master.py]
2026-07-16 feat: added automated device monitor - camera
2026-07-16 fix: added delay transition time - pipeline stops
    [ocr.py]
2026-07-17 fix: added 10 seconds before capture
    [ocr.py]

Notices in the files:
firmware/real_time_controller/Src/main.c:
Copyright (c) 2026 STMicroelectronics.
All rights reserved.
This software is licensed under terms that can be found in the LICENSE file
